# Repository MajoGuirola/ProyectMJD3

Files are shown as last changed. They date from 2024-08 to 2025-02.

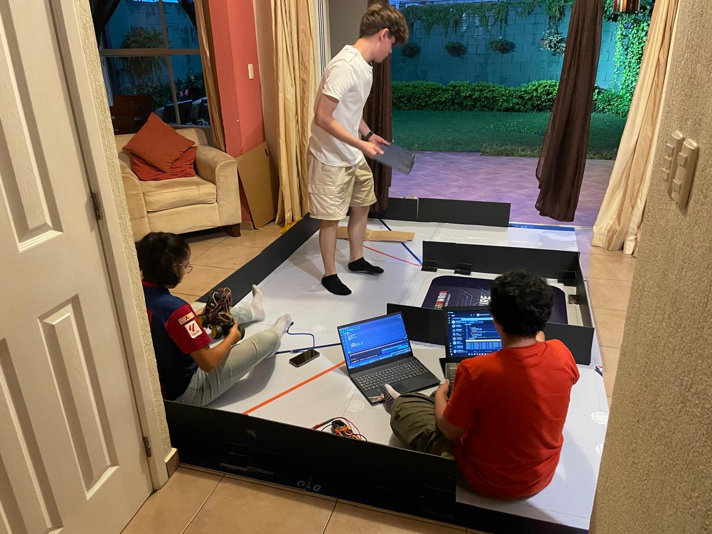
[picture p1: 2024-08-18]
Grupo/TRABAJO GRUPO5.jpeg

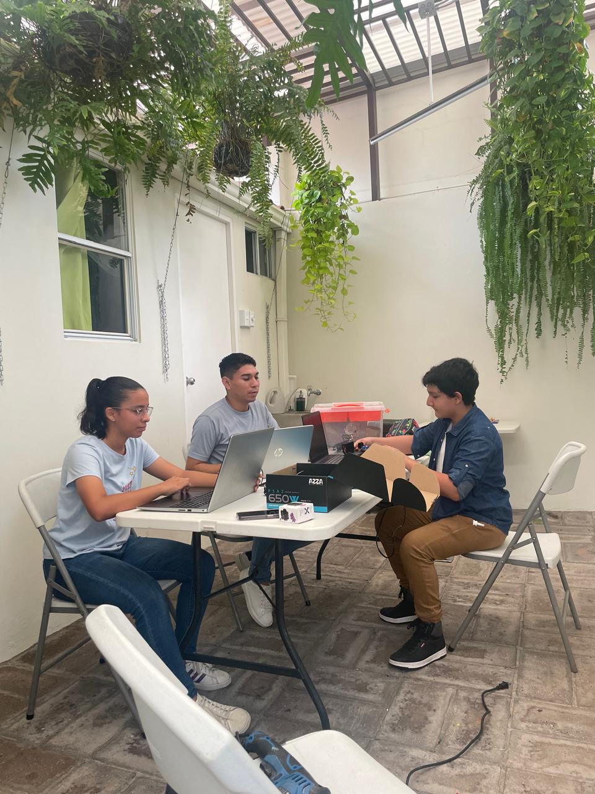
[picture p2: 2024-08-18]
Grupo/TRABAJO GRUPO1.jpeg

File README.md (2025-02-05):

# Proyect MJD3
Proyect for competition WRO 2024 Future Engineers

1.	Introduction
   
We are MJD3, we are young people passionate about robotics and what it entails for the future, our goal as a group is to discover new methodologies in order to solve different problems related to this in the WRO Future Engineers competition.

2. Who we are:

María José Guirola          -    Group Leader, Software and Hardware Developer.

Diego Marcelo Rivera        -                 Software Developer.

Diego Alejandro Rodríguez   -                In charge of the engineering journal.

Diego Alejandro Cartagena   -              Team Coach.

3.	Proyect Status:

Our group engaged the steps of the project with deliberate planning, including reviewing previous competitions. We collected detailed information from each competition, analyzing what skills and knowledge were assessed and what our achievements and learnings were. This informed our group's understanding of the known challenges we would experience in our current competition, as it aligned with which strategies/approaches we would build upon. Once we compiled all the information, we methodically reviewed the competency documentation, laying the groundwork to have everything understood in advance. Especially the rules, technical specifications and evaluation criteria. This positioned our team to have a firmer backing to make decisions, particularly with respect to components selection. We conducted a rigorous evaluation of our components available to us on the market, considering feasibility, price and compatibility tests on such components with our project. From this, we selected the best components that suited our needs and budget. Once we identified the best components we had to initiate our design process. Our group utilized a digital design capability to establish a model of the electronic circuit, with one of the best advantages of digital design was being able to visualize, anticipate and adapt possible challenges before developing our flying robot in physical reality. The development began physically our robot with the chassis. During the build we worked through many design changes with respect to the steering system due to space, strength, and speed of making the change; and later issues with regards to, voltage and current, false connection, frying Arduinos etc. By working through adjustments, many times constructive change through trying to improve the form and integration of our components to our power supply. Simultaneously we started with programming modules. We worked on our code with limited hardware, the electronic design tool, and while we helped achieve some stability.

The construction of our chassis was an unprecedented endeavor that we faced with diligence and determination. From the very beginning, we ensured that the wheels would slip not at all as the vehicle moved - this was critical to the vehicle's stability and steering performance. We did a number of tests on this subject, used a variety of materials and joined pieces in different ways, each trial led to a very efficient traction system. We also worked hard to ensure that the action system worked both precise and accurately; hence the vehicle's ability to perform complex movements was both forceful and defensible. We could not have developed a level of control and precision without a million tests. Yet the iterations laid the groundwork for a world of confidence to approach project challenges with creativity moving forward.

4.1. Enery Supply Distribution:

We find out that our components occupied the following amperage and voltage:

Captura de pantalla 2024-08-30 014126

The batteries we decided would meet our needs would be the 18650, these have between 3.7V and 4.2V and between 8800mAH and 9800mAH. So we decided to place our entire circuit in parallel except for the batteries since the battery holder was in series, thus giving us each battery holder a supply of 8V and 8800mAh maximum.
We used two battery holders with each battery holder distributing power to the following components:

Captura de pantalla 2024-08-30 014020

The 4015 voltage regulator is also used to prevent damage to the Arduino due to a higher voltage than it can withstand.

To begin, we must know what materials we have decided to use, and they are the following:

Captura de pantalla 2024-08-30 013600

Circuito de conexiones

In general we use the rubber bands to generate “grip” on the tires, since without this they slide on the track. The servo motor is to give direction to the car, the servo is anchored with a 3.5cm bolt to a piece printed with PLA that has connected the tires, thus performing the rotation of the tires. The motor has in its axis a gear of 3cm diameter, and the gear of the wheels axis measures 3cm allowing its rotation in reverse direction. In case we need more light in the competition for the part 1, we will use a flashlight extra that will have it´s own powerbank.

OIP

4.2.1.   Open Challenge

Our car uses three distance sensors to decide its direction of turn depending on the value shown by these sensors, so it either makes a turn or not. If none of the sensors shows that it is more than 100 cm away, the car continues straight. If one of the sensors shows that it is too close to a wall, it turns away from the nearest wall to avoid hitting it. If a sensor shows more than 100 cm away from a wall, we decide that the car turns towards the side of the space; that is, if the space is on the left side, it turns left, and the same with the right side. Each time it turns, one is added to a variable that counts the turns. This variable is divided to calculate the turns the car has made. When the turns reach 3, the car stops.

Diagrama de flujo Desafio Abierto

4.2.2. Obstacle Challenge

The Arduino first detects which object has been detected, whether green or red. When it has that value, it classifies it into 3 positions: if it is in the center, on the left, or on the right. If it is the green rectangle that has to turn left and the rectangle is on the right, the car will advance. If the green rectangle is in its center, it will maneuver to avoid it and return to its position. If the rectangle is on its left side or is very close, the car will go back or start to turn to the left side or it will also go back until the object is centered to do the maneuver to avoid it. The distance sensor reads if there is no wall to its left or right and turns to the side where there is no wall and adds it to the turn variable. At the end of the 3 turns, it will start to look for the parking space. When it detects the parking space, it will look for the best way to enter.

Diagrama de flujo Desafío con Obstáculos (1)

The Youtube videos are in these links:

- Open Challenge: https://www.youtube.com/watch?v=KbBiJAI5IG0
- Obstacle Challenge: https://youtube.com/shorts/LHwaTd2JDXg?si=Wgfol8oHPcuWUJ5E

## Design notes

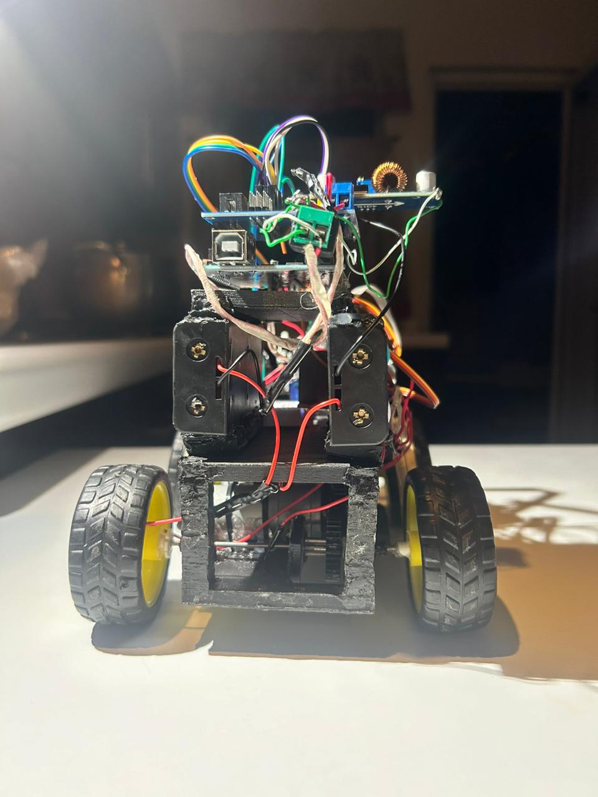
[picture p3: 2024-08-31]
Carro/Carro Atras.jpg

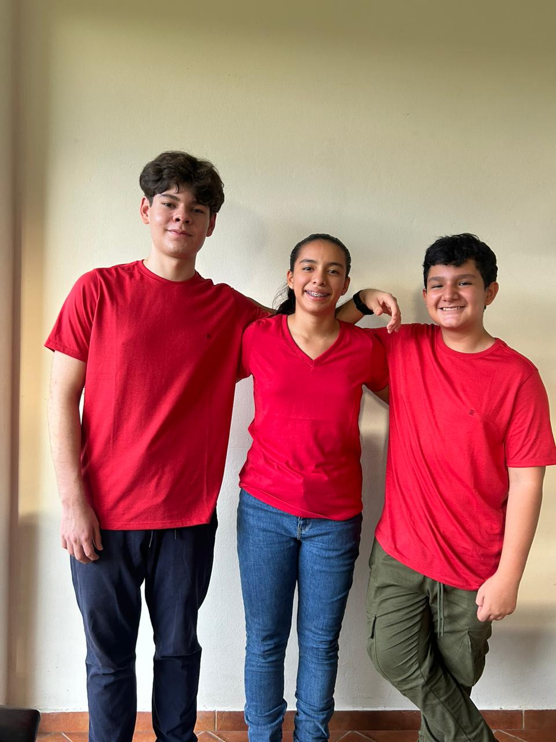
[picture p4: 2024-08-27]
Grupo/TRABAJO GRUPO8.jpeg

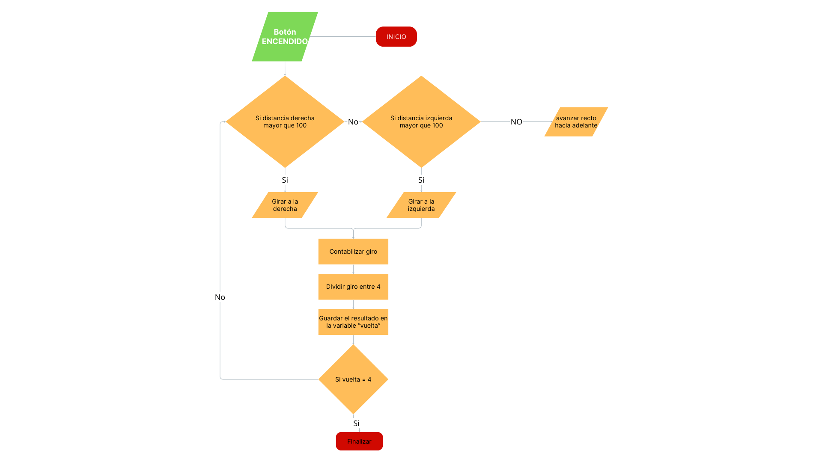
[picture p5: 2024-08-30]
Diagramas/Diagrama de flujo Desafío Abierto.png

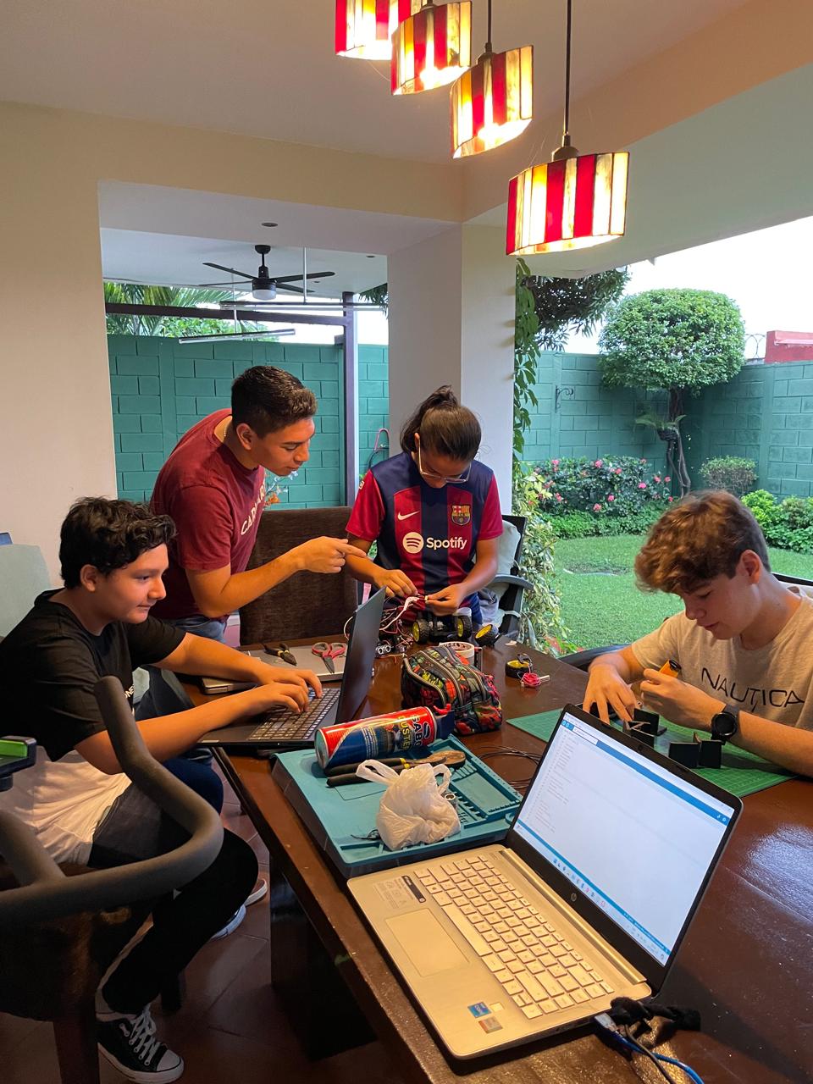
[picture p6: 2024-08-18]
Grupo/TRABAJO GRUPO4.jpeg

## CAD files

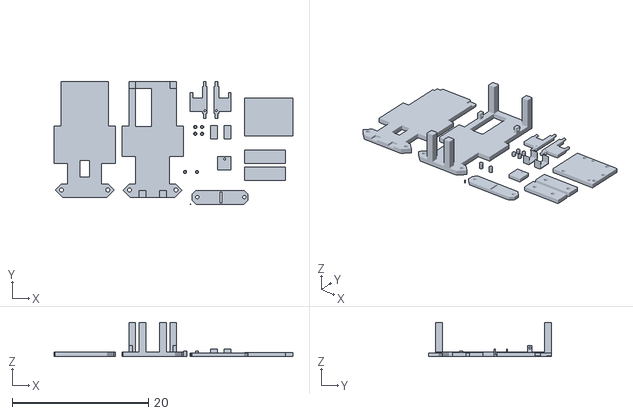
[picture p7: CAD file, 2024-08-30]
Carro/Chasis.stl
35.1 x 18.0 x 5.00

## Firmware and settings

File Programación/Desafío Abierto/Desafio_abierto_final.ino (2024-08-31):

//inclusión de las librerias a utilizar
#include <Servo.h>

//configuracion de pines de los sensores de distancia
#define trigPin2 7
#define trigPin3 6
#define trigPin4 10
#define echoPin2 9
#define echoPin3 8
#define echoPin4 11

int pulsadorPin = 5; // Variable que guarda el número del pin al que conectamos el pulsador.
int valorPulsador = 0; // Variable donde almacenaremos la lectura del estado del pulsador.
int k; //valor que almacenara si se pulso el botón o no

//Configuracion de los pines de los motores (cc y servo)
#define motorPin1 2
#define motorPin2 4
#define servoPin 3

//nombre del serovmotor
Servo direccion;

//todas las variables para los sensores de dirrecion
long duration, distance;

long durationAde = 0;
long durationAtras = 0;
long durationIzq = 0;
long durationDerch = 0;

long distanceAde= 0;
long distanceAtras = 0;
long distanceIzq = 0;
long distanceDerch = 0;

//variables para los if
int a = 0;
int i = 0;
int z= 0;
int d;
int motor;



//variables para el conteo de vueltas
int giro;
int vuelta;

void setup() {
  //inicialización de todos los pines
  Serial.begin(9600);
  pinMode(trigPin2, OUTPUT);
  pinMode(trigPin3, OUTPUT);
  pinMode(trigPin4, OUTPUT);
  pinMode(echoPin2, INPUT);
  pinMode(echoPin3, INPUT);
  pinMode(echoPin4, INPUT);

  pinMode(motorPin1, OUTPUT);
  pinMode(motorPin2, OUTPUT);

  direccion.attach(servoPin);

  pinMode(pulsadorPin, INPUT_PULLUP); // Declaramos la variable inputPin como entrada y activamos su resistencia interna Pullup.
}

void loop() {
  valorPulsador = digitalRead(pulsadorPin);  // Lectura digital de pulsadorPin
  if (valorPulsador == HIGH) {
    k = k;
  }
  else {
    k = 1;
  }
  //si el pulsador fue activado entonces ejecutar el código
  if(k == 1){
  //leer las distancia de los sensores
  leerdistancia();
  //contar cuantas vueltas he dado en base a los giros realizando una división
  vuelta = giro/4;
  Serial.print("giros: ");
  Serial.print(giro);
  Serial.print("  vueltas:");
  Serial.println(vuelta);
    //si no  ha completado las 3 vueltas entonces...
   if (vuelta < 3){
  //si no hay pared del lado derecho entonces girar hacia la derecha
   if (distanceDerch>distanceIzq) {
    if(distanceDerch>100){
    direccion.write(50);
    avanzar();
    delay(3500);
    adelante();
    delay(3000);
    giro = giro + 1;
    distanceDerch=0;
    distanceIzq= 0;
    }
  }
  //si hay escpacio hacia la izquierda entonces girar hacia la izquierda
  if (distanceIzq>100) {
    direccion.write(140);
    avanzar();
    delay(3500);
    adelante();
    delay(3000);
    giro = giro + 1;
    distanceDerch=0;
    distanceIzq= 0;
    Serial.println("izquierda");
  }
  /*
  //si esta muy pegado hacia la derecha entonces centrarse
  else if (distanceDerch < 20){
    direccion.write(110);
    avanzar();
    vueltaContada = false; // Resetea la variable cuando se cambia el estado
  }
  //si esta muy pegado hacia la izquierda entonces centrarse
  else if (distanceIzq < 20){
    direccion.write(80);
    avanzar();
    vueltaContada = false; // Resetea la variable cuando se cambia el estado
  }*/
  //si esta centrado que siga derecho
   else{
    adelante(); 
   }
  }
 //si se completaron las vueltas que se posicione al comienzo y que se finalize el progama al terminar
 if (vuelta == 3){
  stop();
  digitalWrite(motorPin1,LOW);
  digitalWrite(motorPin2,LOW);
 }
 }
}

//lectura de las 3 distancias e imprimirlas en el monitor serial
void leerdistancia(){
  // Sensor 2
  digitalWrite(trigPin2, LOW);
  delayMicroseconds(2);
  digitalWrite(trigPin2, HIGH);
  delayMicroseconds(10);
  digitalWrite(trigPin2, LOW);
  duration = pulseIn(echoPin2, HIGH);
  distance = duration * 0.034 / 2;

  distanceDerch = distance;
  
  Serial.print("Sensor 2: ");
  Serial.print(distanceDerch);
  Serial.print(" cm");

  Serial.print("   ");
  
  duration = 0;
  distance = 0;

  // Sensor 3
  digitalWrite(trigPin3, LOW);
  delayMicroseconds(2);
  digitalWrite(trigPin3, HIGH);
  delayMicroseconds(10);
  digitalWrite(trigPin3, LOW);
  duration = pulseIn(echoPin3, HIGH);
  distance = duration * 0.034 / 2;
  distanceIzq = distance;
  
  Serial.print("Sensor 3: ");
  Serial.print(distanceIzq);
  Serial.print(" cm"); 

  Serial.println("   ");
  
  duration = 0;
  distance = 0;
}

//rectificar las llantas y avanzar
void adelante(){
  direccion.write(104); // Posición del servo para avanzar

  digitalWrite(motorPin1,LOW);
  digitalWrite(motorPin2,HIGH);
}

//solamente avanzar con la posicion de llantas anteriormente establecida en el código
void avanzar(){
  digitalWrite(motorPin1,LOW);
  digitalWrite(motorPin2,HIGH);
}

//detenerse totalmente
void stop(){
  digitalWrite(motorPin1,LOW);
  digitalWrite(motorPin2,LOW);
}

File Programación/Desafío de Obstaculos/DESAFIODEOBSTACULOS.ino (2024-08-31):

//inclusión de las librerias a utilizar
#include <SPI.h>
#include <Pixy2.h>
#include <Servo.h>

//nombre de la pixy
Pixy2 pixy;
//nombre del serovmotor
Servo direccion;

////////////////////////////////////////////////////////

// Pines del motor DC y del servomotor
int motorPin = 4;
int servoPin = 3;
//Configuracion de pines de los botones de inicio
#define buttonPin 5
//configuracion de los pines del sensor de distancia
#define trigPin2 7
#define trigPin3 6
#define echoPin2 9
#define echoPin3 8
////////////////////////////////////////////////////////

//variables para el uso de la cámara
int cont = 0;
int signature, x, y, width, height;
float area;

//variables para el botón de incio
int pulsadorPin = 5; // Variable que guarda el número del pin al que conectamos el pulsador.
int valorPulsador = 0; // Variable donde almacenaremos la lectura del estado del pulsador.
int k = 0;

//variables para contabilizar las vueltas y giros
int giro;
int vuelta;

//variables para los bucles if
int c;
int l;

//variable para almacenar la signature
int j;
//variables para almacenar los angulos del servomotor
int m;
int n;

//variables para la lectura del servomotor
long distanceIzq = 0;
long distanceDerch = 0;
long durationIzq = 0;
long durationDerch = 0;
long duration, distance;

void setup() {
  //inicializando el monitor y la cámara
  Serial.begin(9600);
  Serial.print("Starting...\n");
  pixy.init();

  //declarando pines
  pinMode(motorPin, OUTPUT);
  direccion.attach(servoPin);
  pinMode(trigPin3, OUTPUT);
  pinMode(trigPin2, OUTPUT);
  pinMode(echoPin3, INPUT);
  pinMode(echoPin2, INPUT);

  pinMode(pulsadorPin, INPUT_PULLUP); // Declaramos la variable inputPin como entrada y activamos su resistencia interna Pullup.
}

void loop() {
  //lectura del pulsador
  valorPulsador = digitalRead(pulsadorPin);
  if (valorPulsador == HIGH) {
    k = k;
  }
  else {
      k = 1;
  }
  //si el pulsador fue activado entonces ejecutar el código
  if(k == 1){
    vuelta = giro/4;
  //obtenemos valores de la función
  pixyCheck();
  leerdistancia();
  //si el objeto esta cerca entonces...
  if(vuelta>3){
  if(y>= 30){
    //si es el rectángulo verde entonces..
    if(signature==1){
      Serial.println("VERDE CERCA");
      j= 1;
    }
    //si es el rectángulo rojo entonces..
    if(signature==2){
      Serial.println("ROJO CERCA");
      j= 2;
    }
  }

  //si el sensor derecho marca espacio entonces girar a la derecha 
  if(distanceDerch>110){
    //espera un tiempo para no hacer un giro demasiado cerrado
    avanzar();
    delay(600);
    //luego realiza el giro de 90 grados
    direccion.write(50);
    avanzar();
    delay(3500);
    //suma la vuetla
    giro = giro + 1;
    //restablece los valores
    distanceDerch= 0;
    Serial.println("Derecha");
  }
  //si el espacio esta hacia la izquierda entonces girar hacia la izquierda
  if (distanceIzq>110) {
    avanzar();
    delay(600);
    direccion.write(140);
    avanzar();
    delay(3500);
    giro = giro + 1;
    distanceIzq= 0;
    Serial.println("izquierda");
  }
  else if(j == 1){
    Serial.println("signature 1");
    //si el rectángulo esta totalmente a su derecha entonces solo avanzara
    if(x>=280){
      Serial.println("recto rojo");
      avanzar();
    }
    //si no debera esquivarlo
    else{
      //esquiva el obstaculo en la dirección que deberia
     if(c == 0){
      direccion.write(140);
      n = 50;
      avanzar();
      delay(1800);
      c = 1;
      l=0;
     }
     if(l == 0){
      //avanza un poco para no impactar con el obstáculo
      adelante();
      delay(100);
      //regresa a la posición inicial
      direccion.write(m);
      avanzar();
      delay(1800);
      l=1;
      c=0;
     }
     }
     //restablece las variables
    j = 0;
  }
  else if(j == 2){
    Serial.println("Signature 2");
    //si el rectangulo ya se encuentra totalmente esquivado por defecto entonces solo avanzara
    if(x>=280){
      avanzar();
      Serial.println("Recto verde");
    }
    //si no esta esquivado entonces debera esquivarlo
    else{
    if(c == 0){
      //esquiva el obstáculo en la dirección que debe
     direccion.write(50);
     m = 140;
     avanzar();
     delay(1800);
     c = 1;
     l= 0;  
    }
    if(l == 0){
      //avanza un poco para no impactar con el obstáculo
      adelante();
      delay(100);
      //se reposiciona a la posición icinial
      direccion.write(m);
      avanzar();
      delay(1600);
      l=1;
      c=0;
    }
    }
    //restablecer la lectura para no tener una lectura falsa
    j=0;
  }
  //si no sucede nada de los casos anteriores eso significa de deberia seguir recto
  else{
    Serial.println("sigue recto hasta nueva indicación");
    adelante();
  }
  /*
  Serial.println(j);
  Serial.println(c);
  Serial.println(y);*/
  }
  //si se completan todas las vuetlas, entonces termina de posicionarse y se detiene
  else if(vuelta == 3 ){
    delay(1000);
    stop();
    delay(15000);
  }
  }
}

//leer los valores provenientes de la pixy
float pixyCheck() {
  static int i = 0;
  int j;
  uint16_t blocks;
  char buf[32];
  // grab blocks!
  blocks = pixy.ccc.getBlocks();

  //Si se encuentran bloques, almacenarlos en variables sus valores e imprimirlas
  if (blocks) {
    signature = pixy.ccc.blocks[0].m_signature;
    height = pixy.ccc.blocks[0].m_height;
    width = pixy.ccc.blocks[0].m_width;
    x = pixy.ccc.blocks[0].m_x;
    y = pixy.ccc.blocks[0].m_y;
    Serial.print(" y:");
    Serial.print(y);
    Serial.print(" x:");
    Serial.println(x);
  }
  //si no, todo sera igual a 0
  else {
    signature= 0;
    x= 0;
    y= 0;
    area = 0;
  }
}
//lectura de sensores de distancia
void leerdistancia(){
  // Sensor 2
  digitalWrite(trigPin2, LOW);
  delayMicroseconds(2);
  digitalWrite(trigPin2, HIGH);
  delayMicroseconds(10);
  digitalWrite(trigPin2, LOW);
  duration = pulseIn(echoPin2, HIGH);
  distance = duration * 0.034 / 2;

  distanceDerch = distance;
  
  Serial.print("Sensor 2: ");
  Serial.print(distanceDerch);
  Serial.print(" cm");

  Serial.print("   ");
  
  duration = 0;
  distance = 0;

  // Sensor 3
  digitalWrite(trigPin3, LOW);
  delayMicroseconds(2);
  digitalWrite(trigPin3, HIGH);
  delayMicroseconds(10);
  digitalWrite(trigPin3, LOW);
  duration = pulseIn(echoPin3, HIGH);
  distance = duration * 0.034 / 2;
  distanceIzq = distance;
  
  Serial.print("Sensor 3: ");
  Serial.print(distanceIzq);
  Serial.print(" cm"); 

  Serial.println("   ");
  
  duration = 0;
  distance = 0;
}

//rectificar las llantas y avanzar
void adelante(){
  direccion.write(105); // Posición del servo para avanzar
  digitalWrite(motorPin,HIGH);
}

//solamente avanzar con la posicion de llantas anteriormente establecida en el código
void avanzar(){
  digitalWrite(motorPin,HIGH);
}

//detenerse totalmente
void stop(){
  digitalWrite(motorPin,LOW);
}

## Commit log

2024-06-30 Desafío libre. 29/6/2024.
    Primer sketch de programación para desafío libre.
2024-08-05 Actualización 2
    Optimización en el sistema de navegación en la pista.
2024-08-17 Update README.md
    avance del diario de ingenieria
2024-08-17 Actualización 3
    Añadimos el nuevo sensor MPU6050
2024-08-18 Add files via upload
    Prueba de Trabajo Grupal y Fotos del carro en todos sus ángulos.
2024-08-30 STL del chasis del carro
    [carro wro (13).stl]
2024-08-30 Imagen del circuito electrónico
2024-08-30 STL del Chasis del carro y agregados
    [Chasis.stl]
2024-08-30 Diagrama de flujo Desafío Abierto
2024-08-30 Flujograma desafío abierto
    https://www.canva.com/design/DAGNx8MhYic/FXkPjtSNP90oRbNKZiMf1g/edit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
    para visualizar en grande desde CANVA
2024-08-30 Flujograma desafío con obstáculos
    Anexo enlace a canva para poder visualizarlo mejor
    https://www.canva.com/design/DAGPUDmqfE4/y-bAOhnJwlSza8IzZxUa0g/edit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
